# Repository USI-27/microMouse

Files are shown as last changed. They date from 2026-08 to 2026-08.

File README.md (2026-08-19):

# MicroMouse  Project

This project implements a micromouse robot using a Raspberry Pi Pico W microcontroller. The robot is designed to solve a maze using the flood fill algorithm, with advanced motion control, wall detection, and a custom-designed PCB.

## Repository Structure

```
MicroMouse/
├── MicroMouse Software/       # Firmware source code
│   ├── Headers/                # Header files (.h)
│   ├── images/                 # README images
│   ├── Cell.cpp
│   ├── IR_Sensors.cpp
│   ├── Int_Vector.cpp
│   ├── Maze_Algorithm.cpp
│   ├── Motion_Planner.cpp
│   ├── Profile.cpp
│   ├── Queue.cpp
│   └── Simple_Run_Micromouse_V1.ino
└── MicroMouse Design Files/   # Hardware design files
    ├── mm3.0/                  # KiCad project (schematic + PCB)
    ├── manufacturing/          # Gerbers, drill files, BOM, pick-and-place
    ├── images/                 # PCB and assembly renders
    ├── schematic.pdf
    └── HARDWARE.md             # Detailed hardware documentation
```

## Hardware Implementation

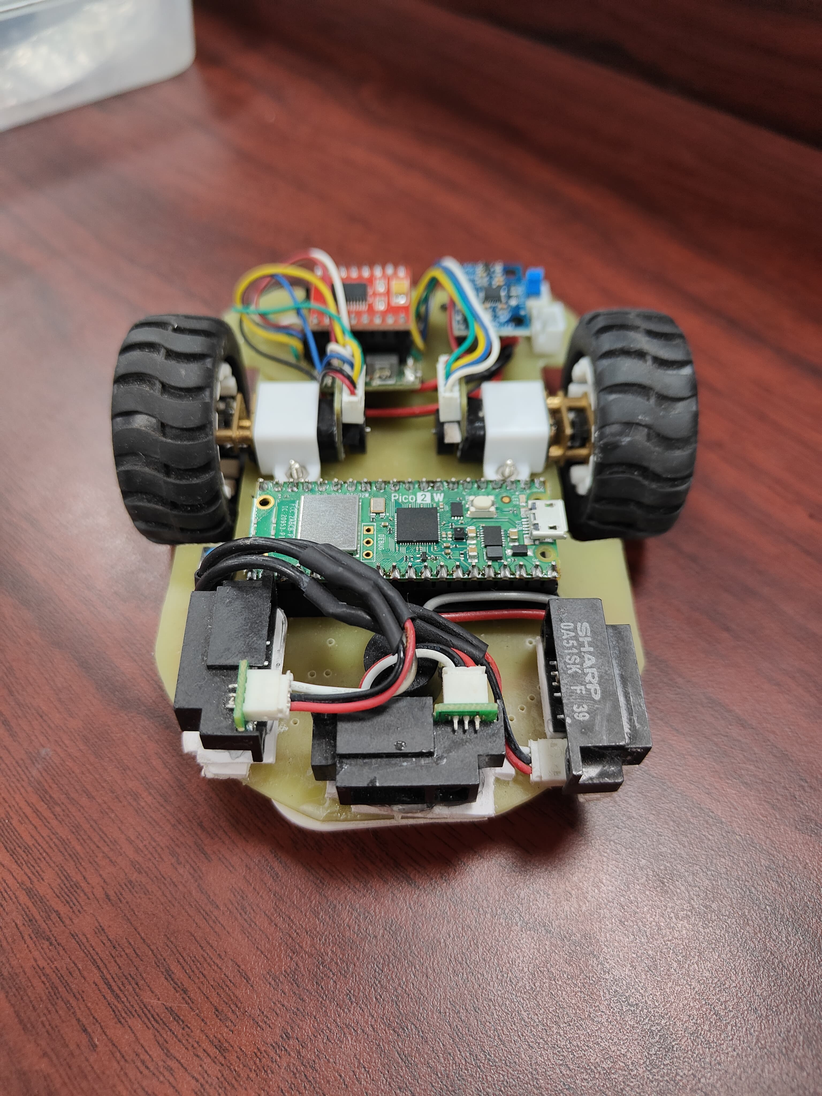
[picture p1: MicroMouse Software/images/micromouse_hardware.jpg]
MicroMouse Hardware


The image above shows the actual hardware implementation of the micromouse robot, featuring:

- Raspberry Pi Pico W at the center
- Dual motor setup with encoders
- IR sensors for wall detection
- Custom PCB design for component integration
- Compact and efficient layout

Full PCB schematics, KiCad source files, manufacturing (Gerber/BOM) files, and design writeups are available in [`MicroMouse Design Files/`](MicroMouse%20Design%20Files/) — see [`HARDWARE.md`](MicroMouse%20Design%20Files/HARDWARE.md) for a detailed breakdown of the sensor placement and board layout.

## Achievements 🏆

- 🥇 **1st Place** at IIT Roorkee's Annual Tech Fest - Cognizance '25, Micromouse Competition (Prize: ₹1,00,000)
- 🥇 **1st Place** at Delhi Technological University's Annual Tech Fest - Invictus '25, Micromouse Competition
- 🥇 **1st Place** at BITS Pilani's Annual Tech Fest - Apogee '25, Micromouse Competition
- 🥉 **3rd Place** at IIT Jodhpur's Annual Tech Fest - Prometeo '25, Micromouse Competition
- 🥉 **3rd Place** at RGIPT's Annual Tech Fest - Urjotsav '24

## Video Demonstration

Check out the micromouse robot in action: [Watch on YouTube](https://www.youtube.com/watch?v=1PZht_hqyYY)

## Hardware Components

- **Microcontroller**: Raspberry Pi Pico W
- **Motors**: 2 DC motors with encoders
- **Sensors**:
  - IR sensors for wall detection (Left, Right, Front)
  - MPU6050 gyroscope for orientation
  - Encoders for distance measurement
- **Motor Driver**: TB6612FNG dual motor driver

## Project Structure (Software)

The firmware is organized into several key components:

1. **Cell.h/cpp** — Defines the maze cell structure and properties
2. **Int_Vector.h/cpp** — Custom vector implementation for sensor data
3. **IR_Sensors.h/cpp** — Wall detection and sensor reading functionality
4. **Maze_Algorithm.h/cpp** — Flood fill algorithm and maze solving logic
5. **Motion_Planner.h/cpp** — Movement control and motor functions
6. **Profile.h/cpp** — Global configuration and pin definitions
7. **Queue.h/cpp** — Queue implementation for flood fill algorithm

## How It Works

### 1. Initialization (`setup()`)

- Configures serial communication
- Initializes MPU6050 gyroscope
- Sets up encoder pins and interrupts
- Configures motor driver pins
- Sets initial maze walls for the starting position

### 2. Maze Exploration Flow

The robot explores the maze in multiple rounds:

```cpp
for (int round = 1; round <= Exploration_Rounds; round++) {
    searchMode = FIND_CENTRE;  // First find the center
    findGoal();
    searchMode = FIND_START;   // Then return to start
    findGoal();
}
```

### 3. Flood Fill Algorithm

The flood fill algorithm works as follows:

1. Initializes all cells with -1 cost
2. Sets goal cells (center or start) with cost 0
3. Propagates costs to neighboring cells
4. Robot moves to the neighboring cell with lowest cost

### 4. Wall Detection

- Uses IR sensors to detect walls
- Updates maze wall information in real-time
- Maintains wall consistency between adjacent cells

### 5. Movement Control

The robot uses several movement functions:

- `moveForward()`: Move one cell forward
- `turnLeft()`: Turn 90 degrees left
- `turnRight()`: Turn 90 degrees right
- Uses PD (Proportional-Derivative) control for smooth motion
- Gyroscope feedback for accurate turns
- Encoder feedback for distance measurement

### 6. Navigation Logic

**Wall Update:**
```cpp
updateWalls();  // Detect and update wall information
```

**Path Planning:**
```cpp
floodOpenNeighbours();     // Update cell costs
getMinDistanceDirection();  // Choose best direction
```

**Movement:**
```cpp
moveInDirection();  // Execute movement
```

## Key Features

**Adaptive Movement:**
- PD control for straight line motion
- Gyroscope-based rotation control
- Wall following capability

**Intelligent Maze Solving:**
- Flood fill algorithm for path planning
- Multiple exploration rounds
- Efficient center finding and return to start

**Robust Sensor Integration:**
- IR sensor filtering
- Encoder-based distance measurement
- Gyroscope-based orientation tracking

## Configuration

Key parameters can be adjusted in `Profile.h`:

- `MAZE_SIZE`: Size of the maze (default: 8x8)
- `Exploration_Rounds`: Number of exploration rounds
- Sensor thresholds
- Motor control parameters

## Usage

1. Upload the code (`Simple_Run_Micromouse_V1.ino`) to the Raspberry Pi Pico W
2. Place the robot at the start position (0,0)
3. The robot will automatically:
   - Find the path to the center
   - Return to start
   - Repeat for the specified number of rounds
   - Make a final run to the center

## Debugging

- LED indicators for status
- Serial output for debugging
- Button to clear maze walls

## Authors

Built by [USI-27](https://github.com/USI-27) and [paramveer5404](https://github.com/paramveer5404) .

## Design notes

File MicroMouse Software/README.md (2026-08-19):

# MicroMouse Robot Project

This project implements a micromouse robot using a Raspberry Pi Pico W microcontroller. The robot is designed to solve a maze using the flood fill algorithm, with advanced motion control and wall detection capabilities.

## Hardware Implementation

MicroMouse Hardware

The image shows the actual hardware implementation of our micromouse robot, featuring:
- Raspberry Pi Pico W at the center
- Dual motor setup with encoders
- IR sensors for wall detection
- Custom PCB design for component integration
- Compact and efficient layout

## Achievements 🏆

- 🥇 **1st Place** at IIT Roorkee's Annual Tech Fest - Cognizance '25, Micromouse Competition (Prize: ₹1,00,000)
- 🥇 **1st Place** at Delhi Technological University's Annual Tech Fest - Invictus '25, Micromouse Competition
- 🥇 **1st Place** at BITS Pilani's Annual Tech Fest - Apogee '25, Micromouse Competition
- 🥉 **3rd Place** at IIT Jodhpur's Annual Tech Fest - Prometeo '25, Micromouse Competition
- 🥉 **3rd Place** at RGIPT's Annual Tech Fest - Urjotsav '24

## Video Demonstration

Check out our micromouse robot in action:

MicroMouse Demo (https://www.youtube.com/watch?v=1PZht_hqyYY)

## Hardware Components

- **Microcontroller**: Raspberry Pi Pico W
- **Motors**: 2 DC motors with encoders
- **Sensors**:
  - IR sensors for wall detection (Left, Right, Front)
  - MPU6050 gyroscope for orientation
  - Encoders for distance measurement
- **Motor Driver**: TB6612FNG dual motor driver

## Project Structure

The codebase is organized into several key components:

1. **Cell.h/cpp**: Defines the maze cell structure and properties
2. **Int_Vector.h/cpp**: Custom vector implementation for sensor data
3. **IR_Sensors.h/cpp**: Wall detection and sensor reading functionality
4. **Maze_Algorithm.h/cpp**: Flood fill algorithm and maze solving logic
5. **Motion_Planner.h/cpp**: Movement control and motor functions
6. **Profile.h/cpp**: Global configuration and pin definitions
7. **Queue.h/cpp**: Queue implementation for flood fill algorithm

## How It Works

### 1. Initialization (setup())
- Configures serial communication
- Initializes MPU6050 gyroscope
- Sets up encoder pins and interrupts
- Configures motor driver pins
- Sets initial maze walls for the starting position

### 2. Maze Exploration Flow
The robot explores the maze in multiple rounds:
```cpp
for (int round = 1; round <= Exploration_Rounds; round++) {
    searchMode = FIND_CENTRE;  // First find the center
    findGoal();
    searchMode = FIND_START;   // Then return to start
    findGoal();
}
```

### 3. Flood Fill Algorithm
The flood fill algorithm works as follows:
1. Initializes all cells with -1 cost
2. Sets goal cells (center or start) with cost 0
3. Propagates costs to neighboring cells
4. Robot moves to the neighboring cell with lowest cost

### 4. Wall Detection
- Uses IR sensors to detect walls
- Updates maze wall information in real-time
- Maintains wall consistency between adjacent cells

### 5. Movement Control
The robot uses several movement function:
- `moveForward()`: Move one cell forward
- `turnLeft()`: Turn 90 degrees left
- `turnRight()`: Turn 90 degrees right
- Uses PD (Proportional-Derivative) control for smooth motion
- Gyroscope feedback for accurate turns
- Encoder feedback for distance measurement

### 6. Navigation Logic
1. **Wall Update**:
   ```cpp
   updateWalls();  // Detect and update wall information
   ```

2. **Path Planning**:
   ```cpp
   floodOpenNeighbours();  // Update cell costs
   getMinDistanceDirection();  // Choose best direction
   ```

3. **Movement**:
   ```cpp
   moveInDirection();  // Execute movement
   ```

## Key Features

1. **Adaptive Movement**:
   - PD control for straight line motion
   - Gyroscope-based rotation control
   - Wall following capability

2. **Intelligent Maze Solving**:
   - Flood fill algorithm for path planning
   - Multiple exploration rounds
   - Efficient center finding and return to start

3. **Robust Sensor Integration**:
   - IR sensor filtering
   - Encoder-based distance measurement
   - Gyroscope-based orientation tracking

## Configuration

Key parameters can be adjusted in `Profile.h`:
- `MAZE_SIZE`: Size of the maze (default: 8x8)
- `Exploration_Rounds`: Number of exploration rounds
- Sensor thresholds
- Motor control parameters

## Usage

1. Upload the code to Raspberry Pi Pico W
2. Place the robot at the start position (0,0)
3. Robot will automatically:
   - Find path to center
   - Return to start
   - Repeat for specified number of rounds
   - Make final run to center

## Debugging

- LED indicators for status
- Serial output for debugging
- Button to clear maze walls

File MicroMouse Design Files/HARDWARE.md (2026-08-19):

# Hardware — Palantir MicroMouse V4

This document covers the custom PCB design, sensor layout, and mechanical assembly for the micromouse robot.

## PCB Overview

The robot runs on a custom two-layer PCB (**Palantir MicroMouse V4**, designed in KiCad 9.0) measuring **99.9963 mm × 61.7300 mm**. The board is built around a Raspberry Pi Pico, with all GPIO pins broken out along one edge for easy access and debugging.

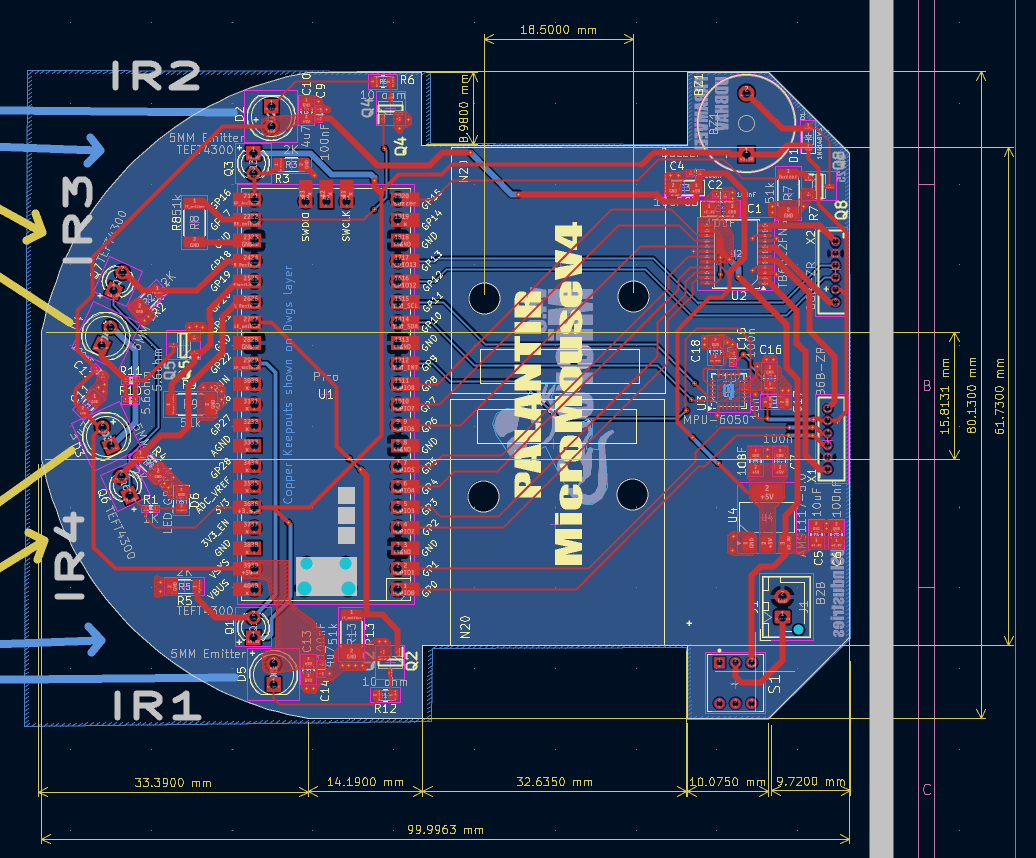
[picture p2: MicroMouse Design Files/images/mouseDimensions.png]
PCB Layout with Dimensions


Key sections on the board:

- **Raspberry Pi Pico footprint** — center-left, with full GPIO breakout (GP0–GP28)
- **IR sensor array** — 4 emitter/receiver pairs (IR1–IR4) along the front-left curve
- **MPU-6050 gyroscope** — right side, for orientation and turn-angle feedback
- **Motor driver section** — right side, driving the dual DC gear-motors
- **Power regulation** — AMS1117 linear regulator with a JST battery connector (bottom right)

## IR Sensor Placement & Sensing Geometry

Sensor placement isn't arbitrary — each IR pair is angled to cover a specific part of the maze cell grid ahead of and beside the robot.

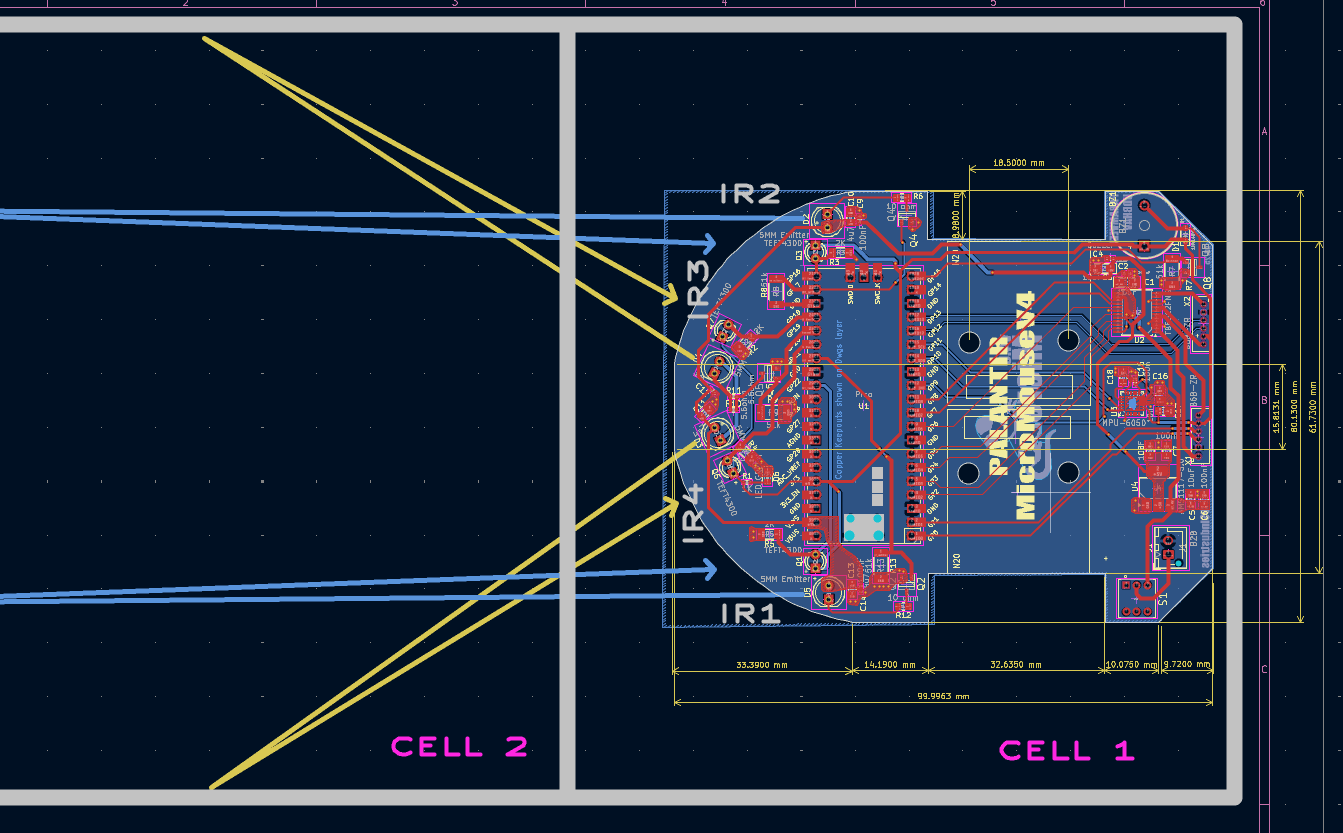
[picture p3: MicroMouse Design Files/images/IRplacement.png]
IR Sensor Placement Diagram


- **IR1 / IR4** (bottom pair) — near-field detection of the front and immediate side walls
- **IR2 / IR3** (top pair) — angled diagonally across the *next* cell, giving early detection of upcoming walls before the robot fully enters a cell

This layout lets the robot start planning its next move before it's even finished crossing the current cell.

## Mechanical Assembly

The 3D render below shows the complete assembly: dual DC gear-motors with encoders mounted symmetrically (top/bottom), the Pico module and IR emitters on the left, and the motor driver, buzzer, and push-button on the right.

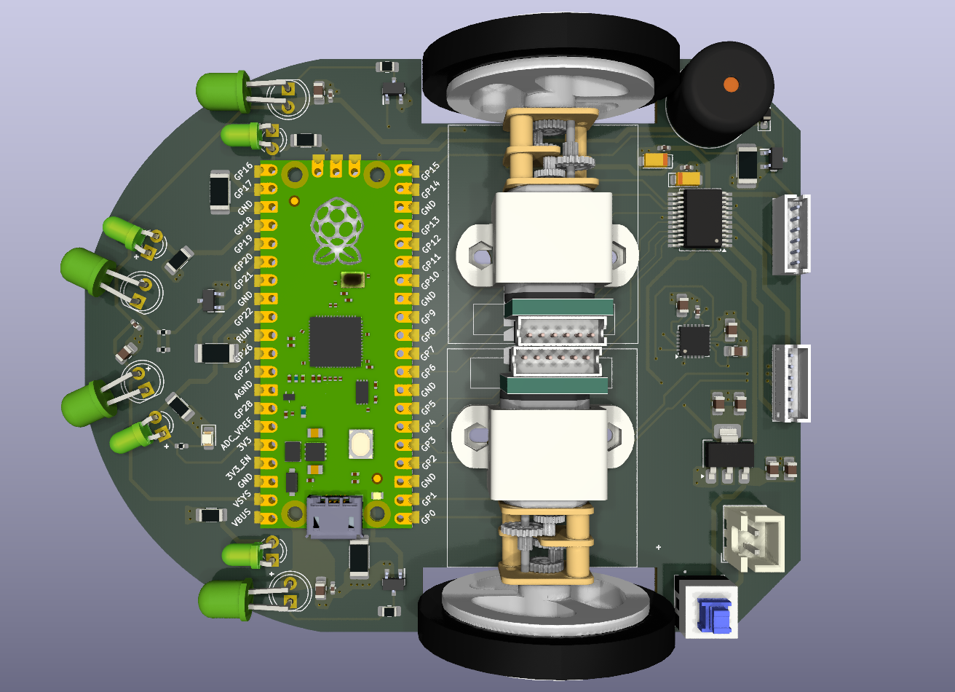
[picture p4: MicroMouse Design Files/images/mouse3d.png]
3D Assembly Render


## Design Files

- `PCB/mm3.0/` — KiCad project (schematic, board file, project libraries)
- `PCB/manufacturing/` — Gerbers, BOM, and pick-and-place files for fabrication

## Bill of Materials (summary)

| Component | Notes |
|---|---|
| Raspberry Pi Pico | Main microcontroller |
| MPU-6050 | Gyroscope for orientation/turns |
| 4x IR emitter/receiver (TEFT4300 + emitter) | Wall detection |
| AMS1117 | 3.3V/5V regulation |
| 2x DC gear-motor w/ encoder | Drive |
| Motor driver IC | Dual motor control |
| JST battery connector | Power input |

## Author
Udbhav Singh

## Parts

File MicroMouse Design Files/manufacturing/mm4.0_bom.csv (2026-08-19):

Designator | Comment | Footprint | LCSC
C1 | 10uF | Capacitor_Tantalum_SMD:CP_EIA-3216-10_Kemet-I_Pad1.58x1.35mm_HandSolder | C7171
C2 | 100nF | Capacitor_SMD:C_0402_1005Metric_Pad0.74x0.62mm_HandSolder | C307331
C3 | 10uF | Capacitor_Tantalum_SMD:CP_EIA-3216-10_Kemet-I_Pad1.58x1.35mm_HandSolder | C7171
C4 | 100nF | Capacitor_SMD:C_0402_1005Metric_Pad0.74x0.62mm_HandSolder | C307331
C5 | 10uF | Capacitor_SMD:C_0805_2012Metric_Pad1.18x1.45mm_HandSolder | C440198
C6 | 100nF | Capacitor_SMD:C_0805_2012Metric_Pad1.18x1.45mm_HandSolder | C495959
C7 | 100nF | Capacitor_SMD:C_0805_2012Metric_Pad1.18x1.45mm_HandSolder | C495959
C8 | 10uF | Capacitor_SMD:C_0805_2012Metric_Pad1.18x1.45mm_HandSolder | C440198
C9 | 4u7 | Capacitor_SMD:C_0805_2012Metric_Pad1.18x1.45mm_HandSolder | C1779
C10 | 100nF | Capacitor_SMD:C_0402_1005Metric_Pad0.74x0.62mm_HandSolder | C307331
C11 | 4u7 | Capacitor_SMD:C_0805_2012Metric_Pad1.18x1.45mm_HandSolder | C1779
C12 | 100nF | Capacitor_SMD:C_0402_1005Metric_Pad0.74x0.62mm_HandSolder | C307331
C13 | 4u7 | Capacitor_SMD:C_0805_2012Metric_Pad1.18x1.45mm_HandSolder | C1779
C14 | 100nF | Capacitor_SMD:C_0402_1005Metric_Pad0.74x0.62mm_HandSolder | C307331
C15 | 100n | Capacitor_SMD:C_0402_1005Metric_Pad0.74x0.62mm_HandSolder | C307331
C16 | 100n | Capacitor_SMD:C_0805_2012Metric_Pad1.18x1.45mm_HandSolder | C495959
C17 | 10n | Capacitor_SMD:C_0805_2012Metric_Pad1.18x1.45mm_HandSolder | C1710
C18 | 2n2 | Capacitor_SMD:C_0805_2012Metric_Pad1.18x1.45mm_HandSolder | C28260
D1 | 1N4148WS | Diode_SMD:D_SOD-323_HandSoldering | C2128
D2 | 5MM Emitter | LED_THT:LED_D5.0mm_IRBlack
D3 | 5MM Emitter | LED_THT:LED_D5.0mm_IRBlack
D4 | 5MM Emitter | LED_THT:LED_D5.0mm_IRBlack
D5 | 5MM Emitter | LED_THT:LED_D5.0mm_IRBlack
D6 | LED_GREEN | LED_SMD:LED_0805_2012Metric_Pad1.15x1.40mm_HandSolder | C2297
J1 | B2B | Connector_JST:JST_XH_B2B-XH-AM_1x02_P2.50mm_Vertical | C158012
J2 | B2B | Connector_JST:JST_XH_B2B-XH-AM_1x02_P2.50mm_Vertical | C158012
Q1 | TEFT4300 | LED_THT:LED_D3.0mm_Clear | C118301
Q2 | DMN1019USN-7 | SPX3819M5-L-5-0:SOT95P285X140-3N | C145103
Q3 | TEFT4300 | LED_THT:LED_D3.0mm_Clear | C118301
Q4 | DMN1019USN-7 | SPX3819M5-L-5-0:SOT95P285X140-3N | C145103
Q5 | DMN1019USN-7 | SPX3819M5-L-5-0:SOT95P285X140-3N | C145103
Q6 | TEFT4300 | LED_THT:LED_D3.0mm_Clear | C118301
Q7 | TEFT4300 | LED_THT:LED_D3.0mm_Clear | C118301
Q8 | DMN1019USN-7 | SPX3819M5-L-5-0:SOT95P285X140-3N | C145103
R1 | 1K | Resistor_SMD:R_0402_1005Metric_Pad0.72x0.64mm_HandSolder | C11702
R2 | 2K | Resistor_SMD:R_1206_3216Metric_Pad1.30x1.75mm_HandSolder | C17944
R3 | 2K | Resistor_SMD:R_1206_3216Metric_Pad1.30x1.75mm_HandSolder | C17944
R4 | 2K | Resistor_SMD:R_1206_3216Metric_Pad1.30x1.75mm_HandSolder | C17944
R5 | 2K | Resistor_SMD:R_1206_3216Metric_Pad1.30x1.75mm_HandSolder | C17944
R6 | 10 ohm | Resistor_SMD:R_0805_2012Metric_Pad1.20x1.40mm_HandSolder | C136903
R7 | 51k | Resistor_SMD:R_2010_5025Metric_Pad1.40x2.65mm_HandSolder | C20435
R8 | 51k | Resistor_SMD:R_2010_5025Metric_Pad1.40x2.65mm_HandSolder | C20435
R9 | 51k | Resistor_SMD:R_2010_5025Metric_Pad1.40x2.65mm_HandSolder | C20435
R10 | 5.6ohm | Resistor_SMD:R_0402_1005Metric_Pad0.72x0.64mm_HandSolder | C25175
R11 | 5.6ohm | Resistor_SMD:R_0402_1005Metric_Pad0.72x0.64mm_HandSolder | C25175
R12 | 10 ohm | Resistor_SMD:R_0805_2012Metric_Pad1.20x1.40mm_HandSolder | C136903
R13 | 51k | Resistor_SMD:R_2010_5025Metric_Pad1.40x2.65mm_HandSolder | C20435
U1 | Pico | MCU_RaspberryPi_and_Boards:RPi_Pico_SMD_TH | C7203003
U2 | TB6612FNG | Package_SO:SSOP-24_5.3x8.2mm_P0.65mm | C141517
U3 | MPU-6050 | Sensor_Motion:InvenSense_QFN-24_4x4mm_P0.5mm | C24112
U4 | AMS1117-5.0 | Package_TO_SOT_SMD:SOT-223-3_TabPin2 | C6187

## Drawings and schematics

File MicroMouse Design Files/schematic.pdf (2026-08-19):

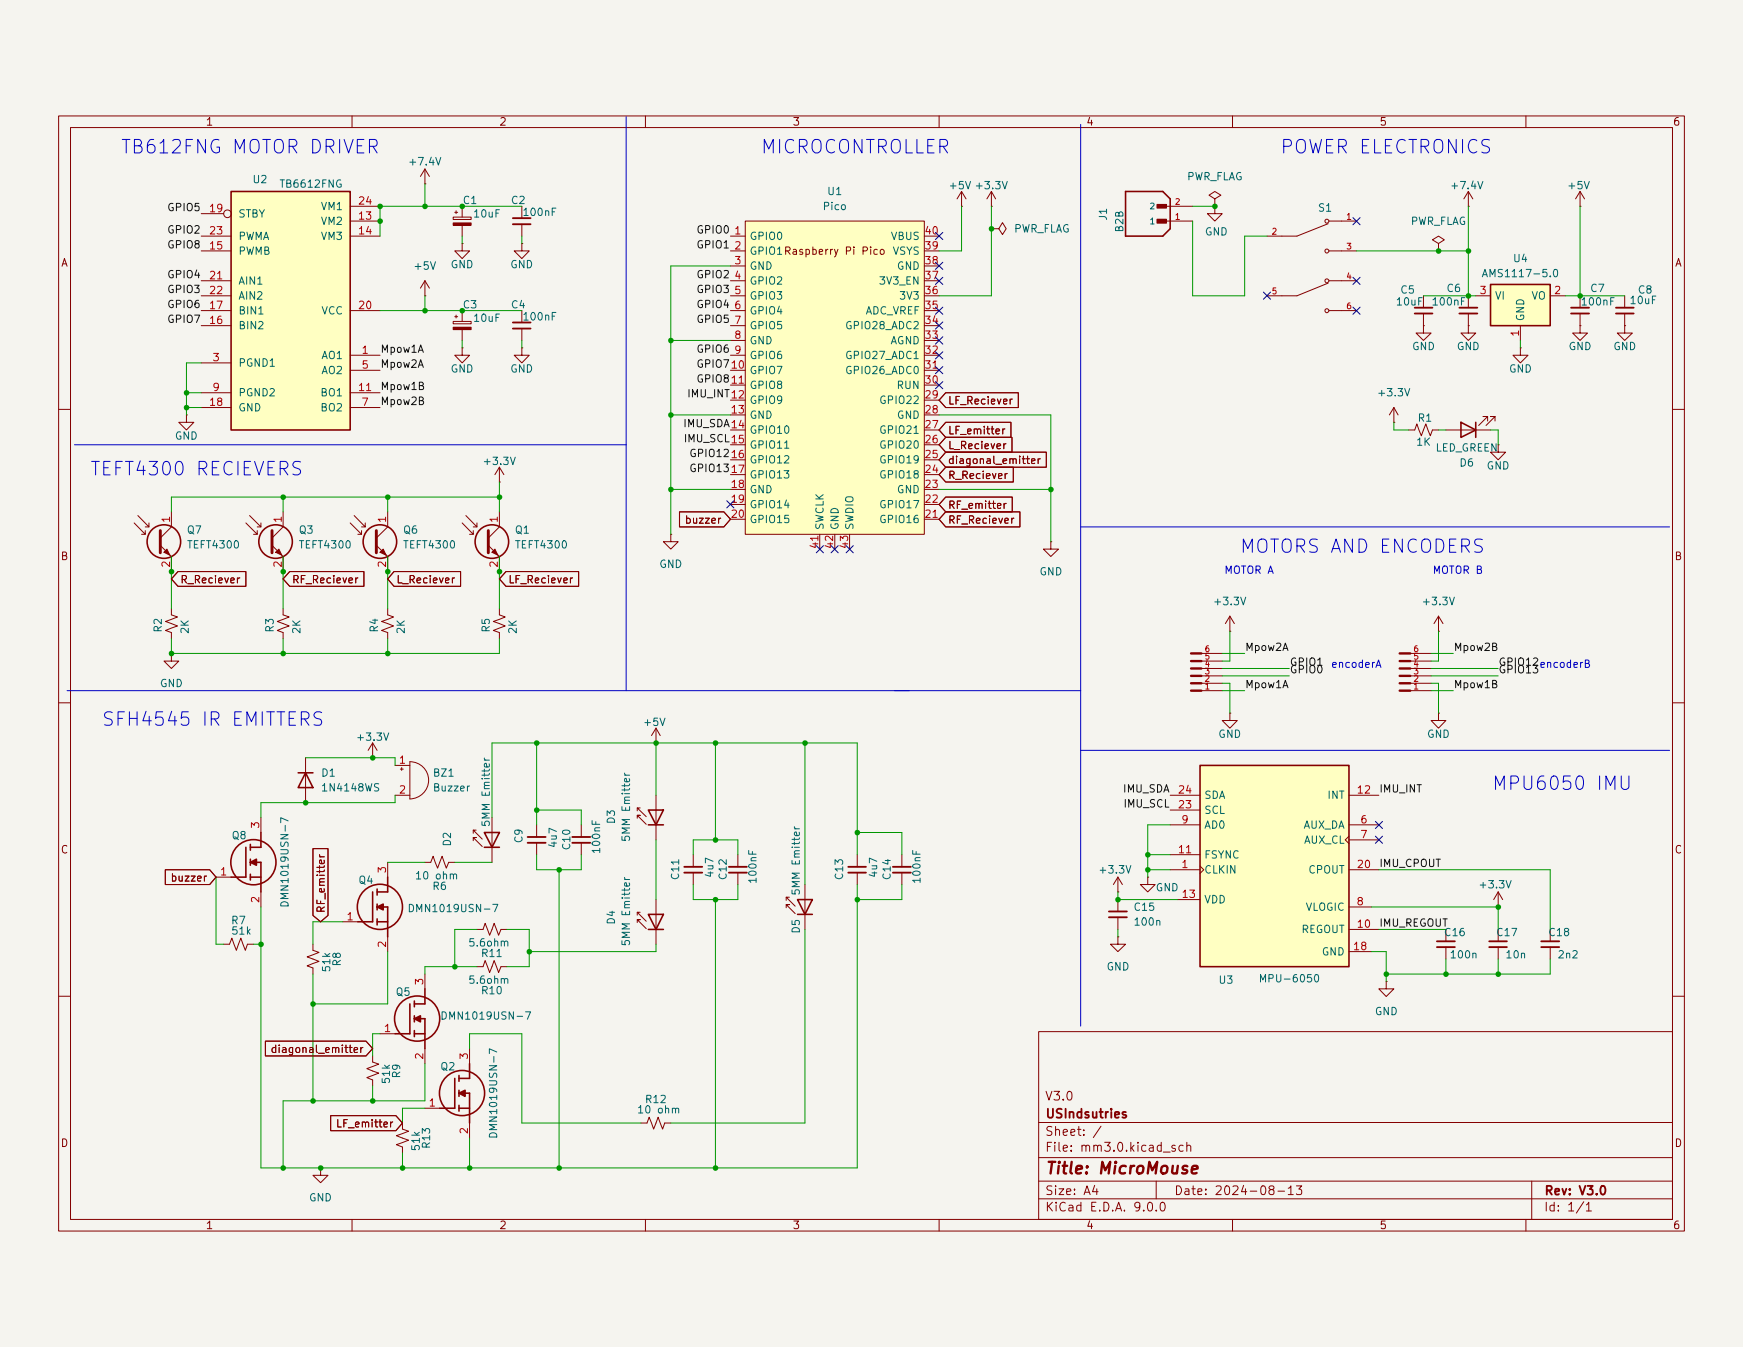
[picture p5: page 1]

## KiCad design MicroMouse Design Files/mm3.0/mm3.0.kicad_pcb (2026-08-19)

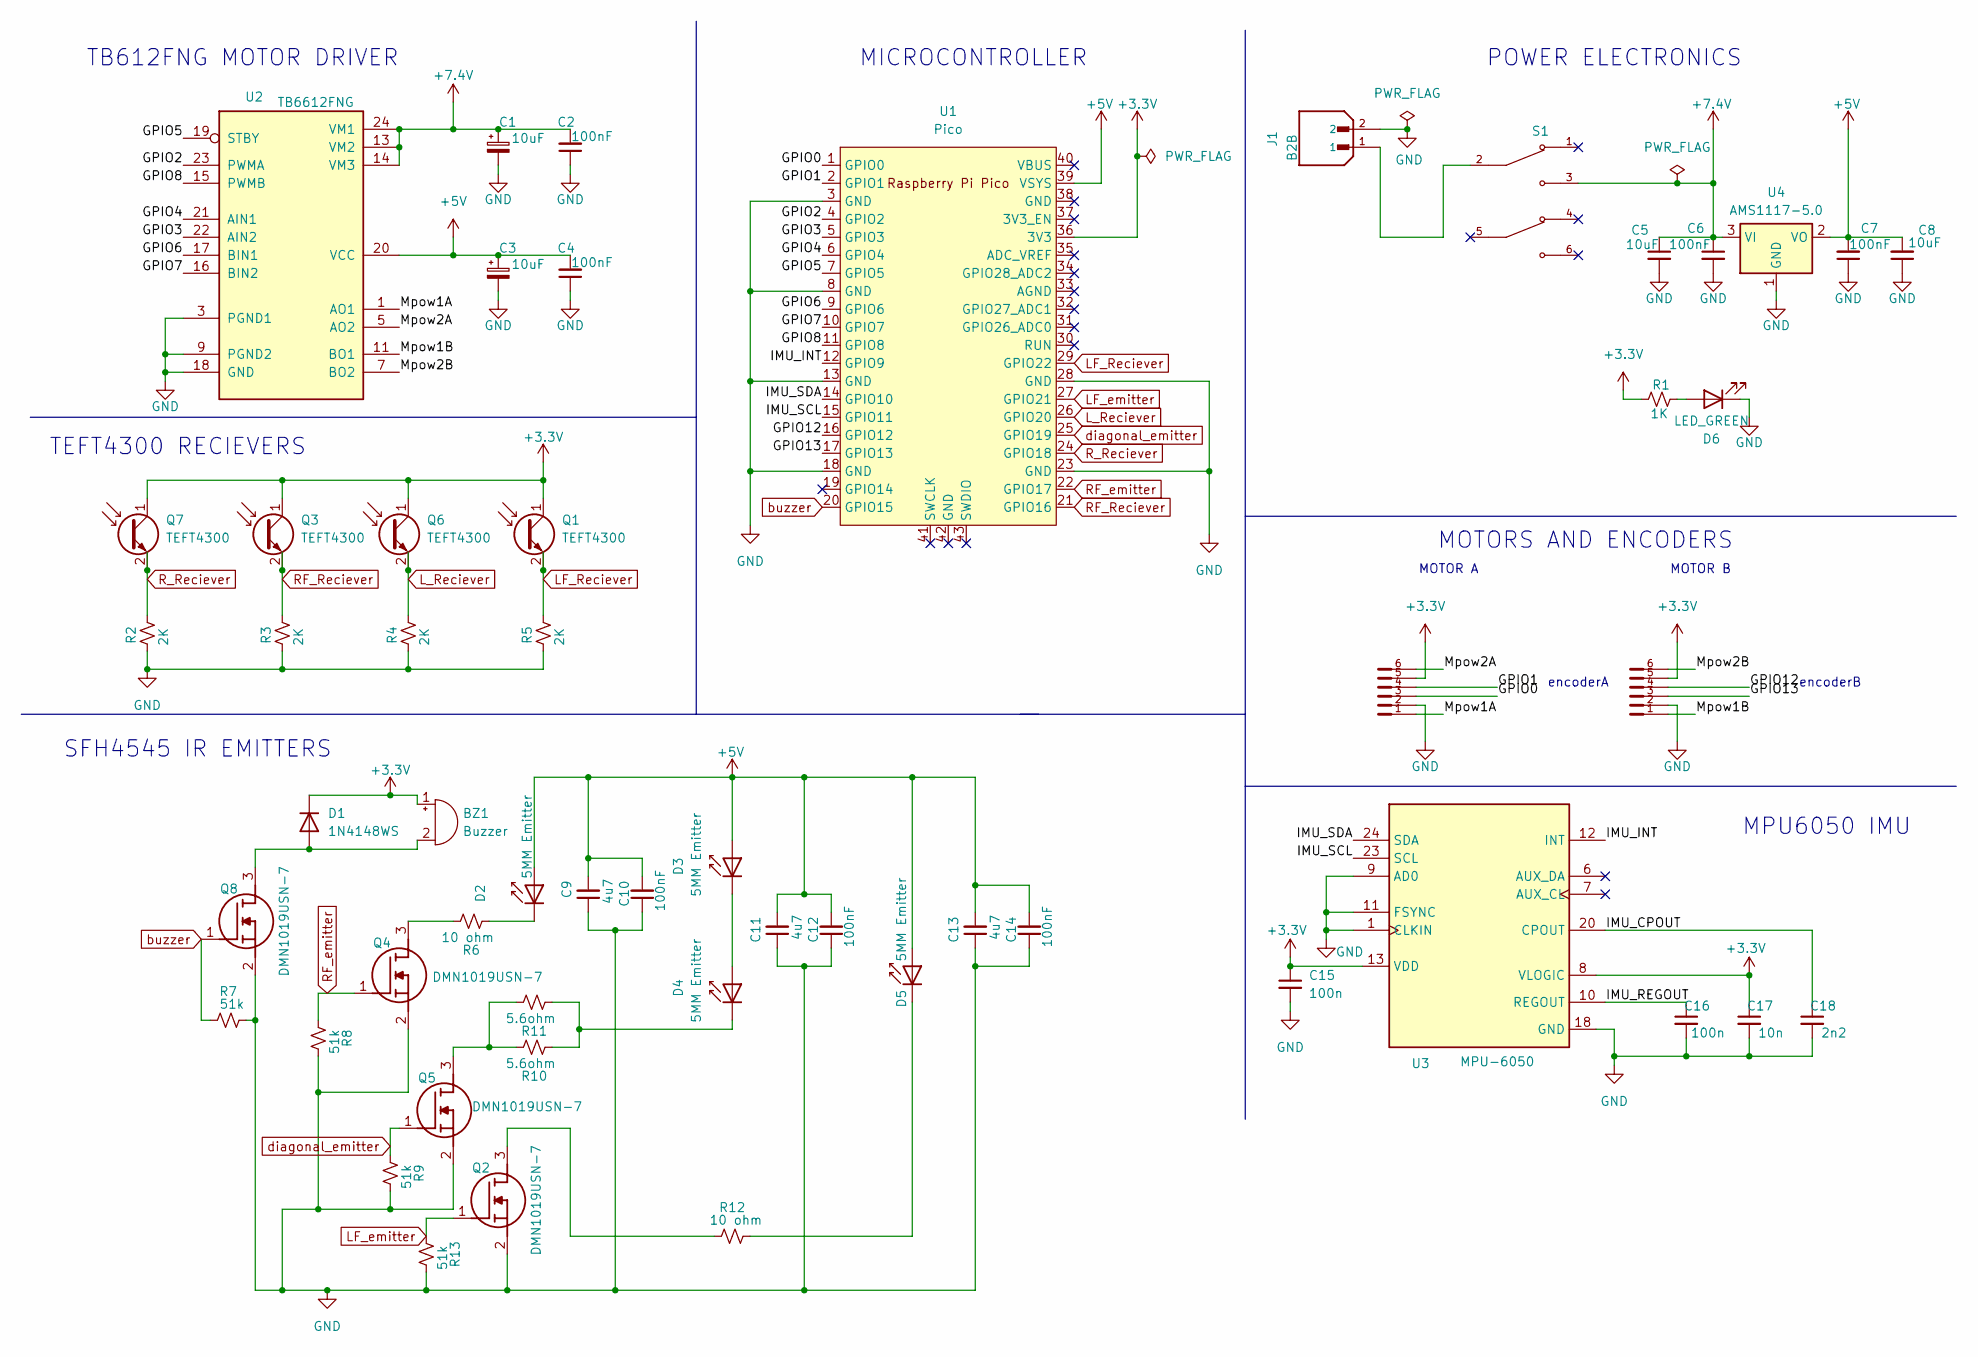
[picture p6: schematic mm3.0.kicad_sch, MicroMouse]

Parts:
BZ1: Buzzer; Buzzer_12x9.5RM7.6
C1, C3: 10uF; CP_EIA-3216-10_Kemet-I_Pad1.58x1.35mm_HandSolder; LCSC C7171
C2, C4, C10, C12, C14: 100nF; C_0402_1005Metric_Pad0.74x0.62mm_HandSolder; LCSC C307331
C5, C8: 10uF; C_0805_2012Metric_Pad1.18x1.45mm_HandSolder; LCSC C440198
C6, C7: 100nF; C_0805_2012Metric_Pad1.18x1.45mm_HandSolder; LCSC C495959
C9, C11: 4u7; C_0805_2012Metric_Pad1.18x1.45mm_HandSolder; LCSC C1779
C13: 4u7; C_0805_2012Metric_Pad1.18x1.45mm_HandSolder
C15: 100n; C_0402_1005Metric_Pad0.74x0.62mm_HandSolder; LCSC C307331
C16: 100n; C_0805_2012Metric_Pad1.18x1.45mm_HandSolder; LCSC C495959
C17: 10n; C_0805_2012Metric_Pad1.18x1.45mm_HandSolder; LCSC C1710
C18: 2n2; C_0805_2012Metric_Pad1.18x1.45mm_HandSolder; LCSC C28260
D1: 1N4148WS; D_SOD-323_HandSoldering; LCSC C2128
D2, D3, D4, D5: 5MM Emitter; LED_D5.0mm_IRBlack
D6: LED_GREEN; LED_0805_2012Metric_Pad1.15x1.40mm_HandSolder; LCSC C2297
J1: B2B; JST_XH_B2B-XH-AM_1x02_P2.50mm_Vertical; PARTREV N/A; LCSC C158012
Q1, Q3, Q6, Q7: TEFT4300; LED_D3.0mm_Clear; LCSC C118301
Q2, Q4, Q5, Q8: DMN1019USN-7; SOT95P285X140-3N; Manufacturer_Part_Number DMN1019USN-7; LCSC C145103
R1: 1K; R_0402_1005Metric_Pad0.72x0.64mm_HandSolder; LCSC C11702
R2, R3, R4, R5: 2K; R_1206_3216Metric_Pad1.30x1.75mm_HandSolder; LCSC C17944
R6, R12: 10 ohm; R_0805_2012Metric_Pad1.20x1.40mm_HandSolder; LCSC C136903
R7, R8, R9, R13: 51k; R_2010_5025Metric_Pad1.40x2.65mm_HandSolder; LCSC C20435
R10, R11: 5.6ohm; R_0402_1005Metric_Pad0.72x0.64mm_HandSolder; LCSC C25175
S1: SW_TL2230EEF140; PARTREV E
U1: Pico; RPi_Pico_SMD_TH; LCSC C7203003
U2: TB6612FNG; SSOP-24_5.3x8.2mm_P0.65mm; LCSC C141517
U3: MPU-6050; InvenSense_QFN-24_4x4mm_P0.5mm; LCSC C24112
U4: AMS1117-5.0; SOT-223-3_TabPin2; LCSC C6187
X1, X2: B6B-ZR; DigiKey_Part_Number 455-B6B-ZR-ND

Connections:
+3.3V: BZ1.1 (+), C15.1, C17.1, D1.1 (K), Q1.1 (C), Q3.1 (C), Q6.1 (C), Q7.1 (C), R1.1, U1.36 (3V3), U3.8 (VLOGIC), U3.13 (VDD), X1.5, X2.5
+5V: C3.1, C4.2, C7.2, C8.2, C9.2, C10.2, C11.2, C12.2, C13.2, C14.2, D2.2 (A), D3.2 (A), D5.2 (A), U1.39 (VSYS), U2.20 (VCC), U4.2 (VO)
+7.4V: C1.1, C2.2, C5.1, C6.1, S1.3, U2.13 (VM2), U2.14 (VM3), U2.24 (VM1), U4.3 (VI)
/GPIO0: U1.1 (GPIO0), X1.3
/GPIO1: U1.2 (GPIO1), X1.4
/GPIO2: U1.4 (GPIO2), U2.23 (PWMA)
/GPIO3: U1.5 (GPIO3), U2.22 (AIN2)
/GPIO4: U1.6 (GPIO4), U2.21 (AIN1)
/GPIO5: U1.7 (GPIO5), U2.19 (STBY)
/GPIO6: U1.9 (GPIO6), U2.17 (BIN1)
/GPIO7: U1.10 (GPIO7), U2.16 (BIN2)
/GPIO8: U1.11 (GPIO8), U2.15 (PWMB)
/GPIO12: U1.16 (GPIO12), X2.4
/GPIO13: U1.17 (GPIO13), X2.3
/IMU_CPOUT: C18.1, U3.20 (CPOUT)
/IMU_INT: U1.12 (GPIO9), U3.12 (INT)
/IMU_REGOUT: C16.1, U3.10 (REGOUT)
/IMU_SCL: U1.15 (GPIO11), U3.23 (SCL)
/IMU_SDA: U1.14 (GPIO10), U3.24 (SDA)
/Mpow1A: U2.1 (AO1), U2.2 (AO1), X1.1
/Mpow1B: U2.11 (BO1), U2.12 (BO1), X2.1
/Mpow2A: U2.5 (AO2), U2.6 (AO2), X1.6
/Mpow2B: U2.7 (BO2), U2.8 (BO2), X2.6
GND: C1.2, C2.1, C3.2, C4.1, C5.2, C6.2, C7.1, C8.1, C9.1, C10.1, C11.1, C12.1, C13.1, C14.1, C15.2, C16.2, C17.2, C18.2, D6.1 (K), J1.2, Q2.2 (S), Q4.2 (S), Q5.2 (S), Q8.2 (S), R2.2, R3.2, R4.2, R5.2, R7.2, R8.2, R9.2, R13.2, U1.3 (GND), U1.8 (GND), U1.13 (GND), U1.18 (GND), U1.23 (GND), U1.28 (GND), U2.3 (PGND1), U2.4 (PGND1), U2.9 (PGND2), U2.10 (PGND2), U2.18 (GND), U3.1 (CLKIN), U3.9 (AD0), U3.11 (FSYNC), U3.18 (GND), U4.1 (GND), X1.2, X2.2
LF_Reciever: Q1.2 (E), R5.1, U1.29 (GPIO22)
LF_emitter: Q2.1 (G), R13.1, U1.27 (GPIO21)
L_Reciever: Q6.2 (E), R4.1, U1.26 (GPIO20)
unnamed: BZ1.2 (-), D1.2 (A), Q8.3 (D)
unnamed: D2.1 (K), R6.1
unnamed: D3.1 (K), D4.2 (A)
unnamed: D4.1 (K), R10.1, R11.1
unnamed: D5.1 (K), R12.2
unnamed: D6.2 (A), R1.2
unnamed: J1.1, S1.2
unnamed: Q2.3 (D), R12.1
unnamed: Q4.3 (D), R6.2
unnamed: Q5.3 (D), R10.2, R11.2
RF_Reciever: Q3.2 (E), R3.1, U1.21 (GPIO16)
RF_emitter: Q4.1 (G), R8.1, U1.22 (GPIO17)
R_Reciever: Q7.2 (E), R2.1, U1.24 (GPIO18)
buzzer: Q8.1 (G), R7.1, U1.20 (GPIO15)
diagonal_emitter: Q5.1 (G), R9.1, U1.25 (GPIO19)

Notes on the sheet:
encoderA
MOTORS AND ENCODERS
POWER ELECTRONICS
MICROCONTROLLER
TB612FNG MOTOR DRIVER
SFH4545 IR EMITTERS
MOTOR B
TEFT4300 RECIEVERS
MPU6050 IMU
encoderB
MOTOR A

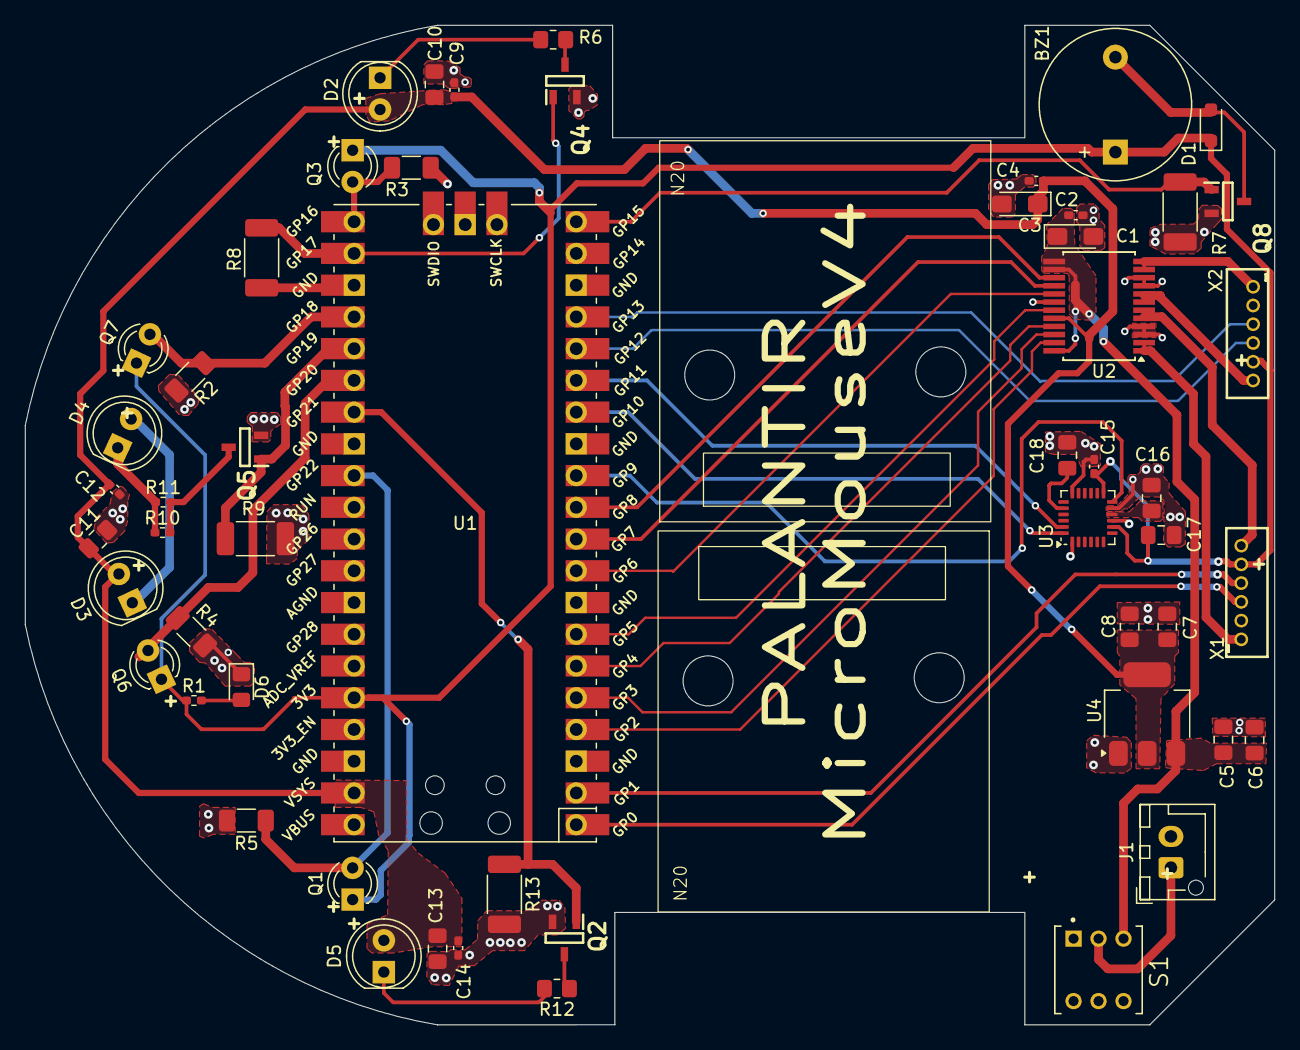
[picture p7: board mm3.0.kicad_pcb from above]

Board: 2 copper layers, 100.0 x 80.0 mm, 57 parts (1 on the bottom side), 42 nets.

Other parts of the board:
N20, N20#2: N20; N20MotorWithMount
logo: LOGO

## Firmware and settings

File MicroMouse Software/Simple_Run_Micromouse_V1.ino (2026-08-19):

#include "Headers/Profile.h"
#include "Headers/Queue.h"
#include "Headers/Cell.h"
#include "Headers/Int_Vector.h"
#include "Headers/IR_Sensors.h"
#include "Headers/Maze_Algorithm.h"
#include "Headers/Motion_Planner.h"


void setup() {
  // Start serial communication for debugging
  Serial.begin(115200);
  Wire.setSDA(0);        // Set SDA to GPIO0
  Wire.setSCL(1);        // Set SCL to GPIO1
  Wire.begin();          // Initialize Wire with specified pins
  
  mpu.begin();           // Start MPU6050 with default Wire object
  Serial.print(F("MPU6050 status: "));
  Serial.println(F("Calculating offsets, do not move MPU6050"));   
  delay(1000);
  mpu.calcGyroOffsets(); // Calibrate gyroscope
  Serial.println("Done!\n");

  // Set up encoder pins as inputs
  pinMode(enc1A, INPUT);
  pinMode(enc2A, INPUT);
  pinMode(enc1B, INPUT);
  pinMode(enc2B, INPUT);
  pinMode(pwmA, OUTPUT);
  pinMode(pwmB, OUTPUT);
  pinMode(ain1, OUTPUT);
  pinMode(ain2, OUTPUT);
  pinMode(bin1, OUTPUT);
  pinMode(bin2, OUTPUT);
  pinMode(stdby, OUTPUT);
  digitalWrite(stdby, HIGH); // Enable the motor driver


  // Set up Wi-Fi LED pin as output
  pinMode(buttonPin, INPUT_PULLUP);
  // Attach an interrupt to the button pin
  attachInterrupt(digitalPinToInterrupt(buttonPin), clearMazeWalls, FALLING);
  pinMode(LED_BUILTIN, OUTPUT);
  digitalWrite(LED_BUILTIN, HIGH);  // Turn on LED


  // Attach interrupts for encoder pins
  attachInterrupt(digitalPinToInterrupt(enc1A), handleEncoderA, CHANGE);
  attachInterrupt(digitalPinToInterrupt(enc1B), handleEncoderB, CHANGE);


  //Assumptions about the first cell
  maze[0][0].setSouthWall(true); 
  maze[0][0].setEastWall(true); 
  maze[0][0].setWestWall(true);
  maze[0][0].setNorthWall(false);
  maze[0][1].setSouthWall(false);
  maze[1][0].setWestWall(true);

  for (int round = 1; round <= Exploration_Rounds; round++) {
    searchMode = FIND_CENTRE;
    findGoal();
    searchMode = FIND_START;
    findGoal();
  }
  searchMode = FIND_CENTRE;
  findGoal();
}

void loop() {}
